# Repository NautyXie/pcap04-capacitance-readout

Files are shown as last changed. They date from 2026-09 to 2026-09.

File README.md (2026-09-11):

# PCAP04 3-Channel Capacitance Readout Board

Open-hardware capacitance-to-digital acquisition board built around the
[ScioSense PCAP04](https://www.sciosense.com/pcap04-capacitance-to-digital-converter/)
CDC and an STM32G0B1. Three floating channel pairs or six grounded electrodes,
brought out on SMA edge connectors, with a single USB-C cable for power,
console and firmware update.

Everything here has been built and measured on real hardware — the numbers in
this README are measurements from an assembled v1.5 board, not datasheet
copy.

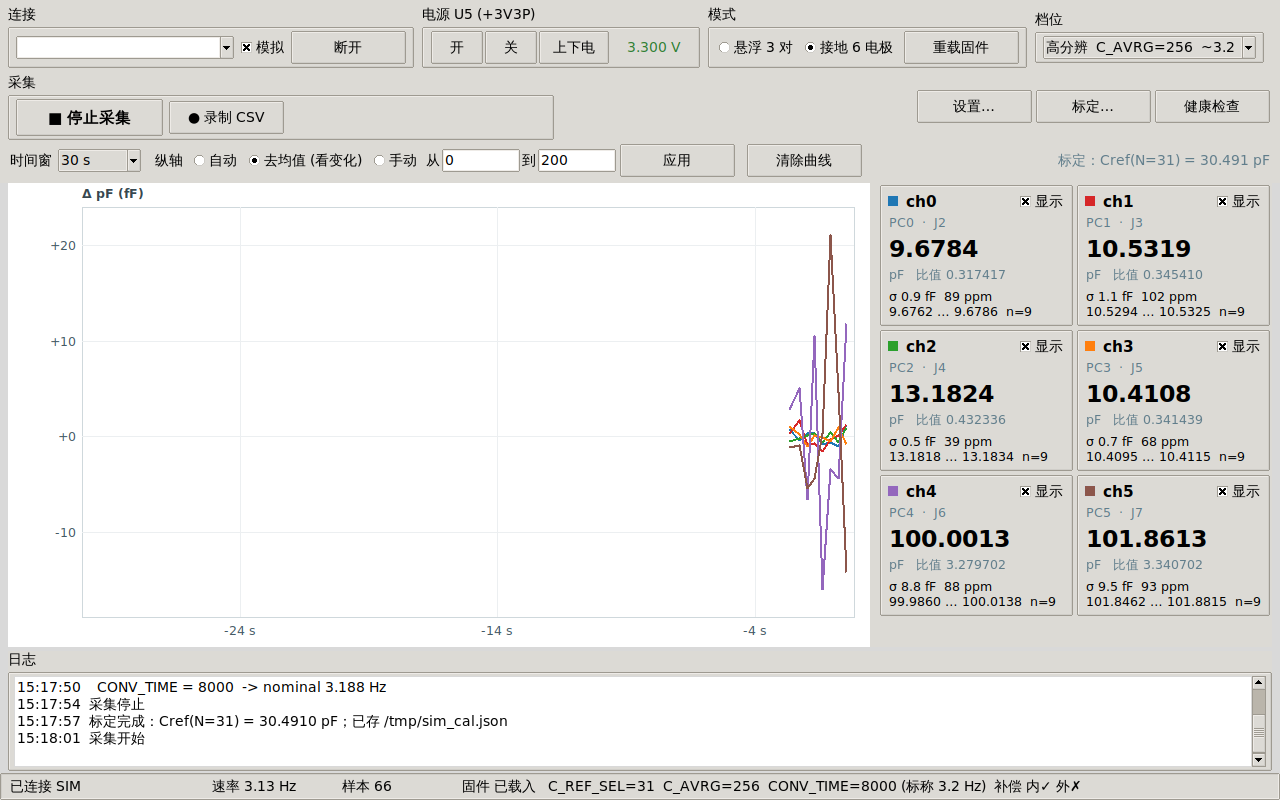
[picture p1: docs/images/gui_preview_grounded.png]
GUI, grounded mode


---

## What it does

| | |
|---|---|
| Channels | 3 floating pairs (PC0/PC1, PC2/PC3, PC4/PC5) **or** 6 grounded electrodes |
| Range | ~385 pF to **1285 pF** full scale, depending on the on-chip reference setting |
| Resolution | sub-aF LSB; **noise floor 4–13 fF** rms depending on averaging and rate |
| Sample rate | 12.8 Hz default, up to **116 Hz** measured |
| Interface | USB-C CDC console (also UART on a header, in parallel) |
| Firmware update | USB DFU — no debug probe needed |
| Board | 100 × 100 mm, 4-layer, SMA edge connectors (C496550) |

Mode switching between floating and grounded takes ~30 ms at runtime; it does
not require re-uploading anything.

## Repository layout

```
hardware/       KiCad 7 project, custom symbols/footprints, 3D models
  manufacturing/  gerbers, drill, IPC netlist
    assembly/       BOM and placement positions
    jlcpcb_pcba/    ready-to-upload JLCPCB assembly packages (BOM + CPL)
firmware/       bare-metal STM32G0B1 firmware (no vendor HAL)
  prebuilt/       pcap04_diag.bin, ready to flash
host/           Python library, CLI and GUI
  characterisation/  the sweeps that produced the numbers in docs/measurements.md
docs/           schematic PDF, design verification report, usage guide,
                measured results
```

## Quick start

### 1. Get a board

`hardware/manufacturing/` contains gerbers, drill files and assembly data ready
to upload. The board is 100 × 100 mm 4-layer; the design rules file is
`hardware/*.kicad_dru`.

For a bare board, upload `PCAP04_v1.5_100mm_C496550_JLCPCB_BARE_BOARD_UPLOAD.zip`.
For an assembled one, use a package under `manufacturing/jlcpcb_pcba/` — but
note that **the PCAP04 itself (LCSC C2829318) is not usually in JLC's assembly
stock and has to be pre-ordered**, and the SMA connectors are hand-soldered.
See [hardware/README.md](hardware/README.md).

### 2. Flash the firmware

No debug probe required — the STM32's ROM bootloader speaks USB DFU, and the
flasher here is pure Python (pyusb, no `dfu-util`):

```bash
cd host
pip3 install -r requirements.txt
python3 pcapdfu.py write ../firmware/prebuilt/pcap04_diag.bin
python3 pcapdfu.py run
```

> A **factory-blank** STM32G0 enters DFU on its own. After the first flash it
> needs one physical unplug/replug of USB-C before it will run your firmware:
> `FLASH_ACR.EMPTY` is only re-evaluated at a power-on reset (RM0444 §2.5.4).
> After that, `python3 pcap.py console dfu` puts it back into DFU on demand.

To build from source you need `arm-none-eabi-gcc`:

```bash
cd firmware && make
```

### 3. Take a measurement

```bash
cd host
python3 pcap.py power on          # U5 load switch -> +3V3P
python3 pcap.py -m f read         # floating, 3 pairs
python3 pcap.py -m g read         # grounded, 6 electrodes
python3 pcap.py stream            # continuous, at the chip's own rate
python3 pcap.py log run.csv -t 60 # 60 s to CSV with running statistics
python3 pcap_gui.py               # graphical strip chart
```

`pcap_gui.py --sim` runs the whole GUI against a built-in simulator, so you can
try the interface before you have a board.

### 4. Calibrate

The chip reports a **ratio** `C / Cref`, so absolute picofarads need one known
capacitor:

```bash
python3 pcap.py calib 100 -c 2    # 100 pF fitted on channel 2
```

Result is stored and loaded automatically from then on.

---

## Things worth knowing before you build one

These cost real debugging time. All measured on the v1.5 board.

**Do not compute Cref from the datasheet formula.** The datasheet gives
`Cref ≈ 0.959·N + 3.23 pF`. This part measures `≈ 0.975·N + 9.91 pF` — the slope
is right to 1.7 % but there is ~7 pF of extra fixed parasitic, and the step
width varies 0.6–1.2 pF between codes (±4 % residual against an affine model).
Calibrate at the code you actually use.

**`DISCHARGE_TIME = 0` breaks real sensors.** The ScioSense reference config
ships with zero discharge time. That is fine for a C0G part on a short trace,
but any sensor with series resistance or a lossy dielectric cannot discharge in
zero time: the port reports `C_PortError` and the reading pins at full scale,
which looks exactly like a dead channel. This firmware defaults to 8. See
[docs/measurements.md](docs/measurements.md).

**`C_AVRG` must stay ≤ 256.** At 512 and above the reading goes ~19.5 % low
(2.4911 → 2.0042 on a 100 pF part). 256 and 257 are both clean, so it is not a
low-byte-zero effect — most likely accumulator saturation with large
capacitances. Firmware and host both clamp.

**A sensor referenced to ground is not a floating sensor.** A level probe
measuring against a tank wall is single-ended. In floating mode the chip
measures the *differential* capacitance between the two ports, and external
compensation deliberately removes each node's capacitance to ground — which is
exactly the signal. The same probe read 0.13 pF floating and 364 pF grounded,
with 36 ppm noise instead of 3800 ppm.

**Config writes need INIT + CDC_START.** Writing a config register alone leaves
the running conversion on the old setting. The first conversion after a restart
is usually garbage (often `0xFFFFFFFF`). The host library handles both.

**The PCAP04's firmware lives in volatile SRAM.** Its NVRAM ships blank, so the
548-byte DSP firmware is uploaded at every power-up. Any reset — a rail cycle or
its own watchdog — zeroes the config registers but **leaves the result
registers holding the previous conversion**, so a dead chip can hand back
plausible-looking stale data. The firmware verifies `RUNBIT` rather than
trusting a cached flag, and the host raises rather than returning stale values.

**Not populated on v1.5:** `PCAUX` (the guard driver output) and the
`PT0REF`/`PT1`/`PTOUT` resistance pins are unrouted, so the integrated guard
driver and external Pt temperature measurement cannot be used on this revision.
`RES6`/`RES7` still return numbers but are only useful as drift indicators.
Route these out if you respin.

---

## Documentation

- [docs/schematic.pdf](docs/schematic.pdf) — rendered schematic, no KiCad needed
- [docs/measurements.md](docs/measurements.md) — every measured figure, and how it was obtained
- [docs/usage.zh.md](docs/usage.zh.md) — full usage guide (Chinese)
- [docs/design-verification-report.pdf](docs/design-verification-report.pdf) — schematic and layout review against the datasheets

## Datasheets

Not redistributed here — they are the vendors' copyrighted documents. Download
from the source:

- PCAP04 — ScioSense
- STM32G0B1 datasheet and RM0444 reference manual — STMicroelectronics
- AN2606 (ROM bootloader) — STMicroelectronics
- TPS22918 load switch, TPS7A20 / TLV755P LDOs, SN74LV125A buffer — Texas Instruments
- USBLC6-2 ESD protection — STMicroelectronics

## Licensing

| Part | Licence |
|---|---|
| `hardware/` | [CERN-OHL-P-2.0](LICENSES/CERN-OHL-P-2.0.txt) |
| `firmware/`, `host/` | [MIT](LICENSES/MIT.txt) |
| `docs/` | [CC-BY-4.0](LICENSES/CC-BY-4.0.txt) |

### Third-party code

`firmware/pcap04_stdfw.h` contains the PCAP04 standard DSP firmware (548 bytes)
and its default configuration (52 bytes), extracted from the
[ScioSense PCAP04 sample code](https://github.com/sciosense/pcap04-sample-code),
which is MIT licensed, **Copyright © 2023 ScioSense**. That copyright notice is
reproduced in the header file. Everything else in `firmware/` is original.

## Contributing

Issues and pull requests welcome. If you build one, a note about what you
measured would be genuinely useful — especially Cref calibration on a different
chip, since the ~7 pF intercept offset documented above is a single-part result
and may or may not be typical.

## Disclaimer

This is a research instrument, published as-is with no warranty. It has been
verified on one assembled board by one person. Check it against your own
requirements before relying on it for anything that matters.

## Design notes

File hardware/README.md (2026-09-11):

# Hardware

KiCad 7 project for the PCAP04 3-channel capacitance readout board.
100 × 100 mm, 4 layers, SMA edge connectors.

Licence: **CERN-OHL-P-2.0** (permissive). See `../LICENSES/CERN-OHL-P-2.0.txt`.

## Files

```
PCAP04_Acquisition_3CH_v1.5_100mm_C496550.kicad_pro   project
                                          .kicad_sch   root sheet
                                          .kicad_pcb   layout
                                          .kicad_dru   design rules
MCU_CONTROL.kicad_sch      STM32G0B1, SWD, USB, console header
USB_POWER.kicad_sch        USB-C input, protection, rails, U5 load switch
PCAP04_Acquisition.lib     custom symbols
PCAP04_Custom.pretty/      custom footprints
sym-lib-table              symbol library table
fp-lib-table               footprint library table
3dmodels/                  3D models for the custom parts
manufacturing/
  gerber/  drill/            bare-board fabrication
  *_JLCPCB_BARE_BOARD_UPLOAD.zip   the same, zipped for upload
  *_IPC-D-356.net            netlist for electrical test
  assembly/                  KiCad BOM (all / fitted) and placement positions
  jlcpcb_pcba/               ready-to-upload JLCPCB assembly packages
    smt_only/                  49 SMT placements, no through-hole
    j11_fitted/                the same plus the J11 power-select header
```

A rendered schematic is at `../docs/schematic.pdf`, and board renders are in
`../docs/images/`, so you can read the design without installing KiCad.

## Getting one made

`manufacturing/` is ready to upload as-is. It was produced for and verified at
JLCPCB, but the gerbers are standard.

- 4 layers, 1.6 mm, HASL or ENIG both fine
- the SMA edge connectors are C496550 (LCSC part number)

For **bare boards**, upload `manufacturing/PCAP04_v1.5_100mm_C496550_JLCPCB_BARE_BOARD_UPLOAD.zip`
and nothing else.

For **assembled boards**, pick one of the two packages under
`manufacturing/jlcpcb_pcba/` and follow the README inside it — each lists the
exact BOM and CPL files to upload and what is deliberately left unfitted. Two
things there are worth reading before you pay:

- **U1 (PCAP04-AQFM-24, LCSC C2829318) is not normally in JLC's assembly
  stock.** It has to be pre-ordered into My Parts Lib. No substitution is
  acceptable.
- **The SMA connectors J2–J7 are not assembled.** They are edge-mount parts;
  solder them by hand. Same for the headers, except J11 in the `j11_fitted`
  package.

`assembly/` holds the plain KiCad exports (BOM and placement positions) if you
want to feed a different assembler or hand-build.

## Layer stack and why it matters here

| Layer | Use |
|---|---|
| L1 F.Cu | components, sense lines |
| L2 In1.Cu | ground plane |
| L3 In2.Cu | power and signal |
| L4 B.Cu | chassis pour |

The sense traces to the SMA connectors want a continuous ground plane directly
underneath. Measured trace capacitance follows

```
C = 4.18 pF + 0.158 pF/mm
```

for five of the six electrodes, within ±3 %. **PC4 is 20 % off** because it is
routed on L4 under the chassis pour rather than over the ground plane. That was
flagged in the design review before assembly and then confirmed by measurement
— see `../docs/measurements.md` §3. Fix it if you respin.

## Known limitations of v1.5

**`PCAUX` is not routed.** That pin is the PCAP04's integrated guard driver
output. Without it, guarding (`C_G_EN`) cannot be used, which matters if you
want long cables to remote electrodes.

**`PT0REF` / `PT1` / `PTOUT` are not routed.** The resistance-to-digital
converter therefore has no external reference resistor, so external Pt
temperature measurement is unavailable. `RES6`/`RES7` still return numbers, but
treat them only as drift indicators.

**RPS1 was assembled as 33 kΩ where the BOM says 330 kΩ.** This is an assembly
deviation on the built board, not a design error — it changes the +3V3P sense
divider to 133/100. The firmware compensates (`board.h`, `RAIL_DIV_NUM`), and
the `div` console command overrides it. Check what is actually fitted on yours.

If you respin, routing `PCAUX` and the PT pins out to test points would be the
two highest-value changes.

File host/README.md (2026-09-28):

# Host tools

Python library, command line and GUI. Licence: **MIT**.

```bash
pip3 install -r requirements.txt
```

`pyserial` is the only hard requirement. `pyusb` + `libusb-package` are needed
for DFU flashing; `pyocd` only if you use a CMSIS-DAP probe over SWD.

## Files

| | |
|---|---|
| `pcap04.py` | the library: `PCap04`, `Sample`, `Calibration` |
| `pcap.py` | command line |
| `pcap_gui.py` | tkinter GUI with a strip chart; `--sim` needs no hardware |
| `pcapdfu.py` | USB DFU flasher, pure Python |
| `pcapflash.py` | SWD flasher via pyOCD (optional) |
| `swdlib.py` | shared pyOCD helpers |
| `characterisation/` | the sweeps behind `../docs/measurements.md` |

## Library

```python
from pcap04 import PCap04

with PCap04() as d:
    d.power(True)
    d.load('f')                     # or d.mode('g') to switch at runtime
    d.speed('precise')
    for s in d.stream(100):
        print(s.pf)                 # [ch0, ch1, ch2] in picofarads
        if s.errors:
            print(s.errors)
```

`Sample` exposes `.raw` `.ratios` `.channels` `.pf` `.status` `.errors`
`.por_flags` `.runbit` `.is_open(i)`.

## Three traps this code exists to avoid

**Console framing.** The firmware prints `> ` when ready. Some commands sit in a
500 ms delay mid-output, so waiting for a silent gap returns early and the *next*
command is written while the firmware is not listening — dropped with no error.
Everything here waits for the prompt.

**Duplicate samples.** Polling faster than the conversion rate re-reads the same
registers, and a naive standard deviation then comes out as exactly 0.
`stream()` is gated on INTN in firmware; `read()` de-duplicates on the raw word;
`stats()` raises rather than reporting zero variance.

**Stale data after a reset.** A PCAP04 power-on reset zeroes the config
registers but leaves the *result* registers holding the previous conversion, so
a dead chip hands back plausible numbers. `read()` checks `RUNBIT` and raises;
pass `allow_stale=True` if you want to inspect them anyway.

There is also an advisory lock on the serial port: two processes opening
`/dev/cu.*` on macOS does not error, it just interleaves bytes and looks exactly
like wedged hardware. Linux/macOS retain this `fcntl` file lock. On Windows,
pyserial opens the serial port exclusively, so no `fcntl` module or lock file
is needed; a second open fails with `serial.SerialException`.

## Calibration

The chip reports `C / Cref`. One known capacitor turns that into picofarads:

```bash
python3 pcap.py calib 100 -c 2            # 100 pF on channel 2
python3 pcap.py calib 100 -c 2 --sweep    # characterise all 31 reference codes
```

Stored in `pcap04_calibration.json` (gitignored — it is specific to your board)
and loaded automatically afterwards.

## Full configuration editor

The GUI **前端参数** button exposes 90 named user fields, including the
10/180 kΩ charging resistor and precharge/full-charge timing. It reads the
actual configuration, pauses acquisition, applies only edits with RUNBIT held
low, verifies readback, and supports JSON snapshots. No firmware reflash is
required. See [configuration controls](../docs/register-controls.md) for timing,
protected fields, CLI/API examples and the hardware-validation boundary.

```sh
python3 pcap.py registers --list
python3 pcap.py registers
```

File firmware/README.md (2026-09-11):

# Firmware

Bare-metal STM32G0B1CBT6 firmware. No vendor HAL, no CubeMX — every register
definition in `stm32g0b1.h` was written by hand against RM0444 Rev 6 and
DS13560 Rev 6.

Licence: **MIT**. `pcap04_stdfw.h` additionally carries ScioSense's MIT notice;
see the top of that file and `../LICENSE`.

## Build

```bash
make                # needs arm-none-eabi-gcc
```

~22 KB of the 128 KB flash. A prebuilt binary is in `prebuilt/`.

## Flash

```bash
cd ../host
python3 pcapdfu.py write ../firmware/prebuilt/pcap04_diag.bin
python3 pcapdfu.py run
```

See the top-level README for the one-time power-cycle caveat on a blank chip.

## Source map

| File | |
|---|---|
| `main.c` | clocks, GPIO, ADC, SPI, PCAP04 driver, console, commands |
| `usb_cdc.c/.h` | USB CDC-ACM device, polled, ~600 lines |
| `stm32g0b1.h` | register definitions, hand-verified against RM0444 |
| `board.h` | pin map, PCAP04 opcodes, board constants |
| `startup.c` | vector table and reset handler |
| `stm32g0b1cb.ld` | linker script; `.noinit` holds the double-tap magic word |
| `pcap04_stdfw.h` | ScioSense DSP firmware + default config (third-party, MIT) |

## Design notes

**Three console transports in parallel** — USB CDC, UART on J10, and an SWD
mailbox — and the main loop reads whichever speaks first. Keeping the UART alive
means a USB regression can never lock you out of the board.

**No interrupts except SysTick.** USB is polled from the main loop, so it cannot
perturb the SPI timing of a conversion in progress. Every hardware wait is
bounded with a per-peripheral timeout rather than a bare `while (!(REG & FLAG))`,
and `info` reports which ones ever fired.

**Escape hatch.** Double-tap RESET within 400 ms and the board enters the ROM
bootloader regardless of what the application firmware is doing. The magic word
lives in `.noinit`. `usb_cdc_detach()` runs first so the ROM's USB comes up on a
clean bus.

**Clocks.** HSI16 → PLL(M=1, N=8, R=÷2) → 64 MHz core, 2 flash wait states.
USB runs from HSI48 trimmed by the CRS against USB SOF packets — there is no
crystal on this board. Note `PLLR` encoding: `001` is ÷2, `000` is Reserved.

## Console commands

`help` lists them all. The ones you will actually use:

```
rail on|off          U5 load switch for the PCAP04 supply
load | loadf         upload the DSP firmware, grounded / floating
mode g|f             switch mode at runtime (~30 ms)
stream [n]           one line per conversion, gated on INTN
resd                 RES0..RES7 as Q5.27 ratios
avrg / conv / refsel / disch / comp / ports    front-end parameters
params               decode the current configuration
health               decode STATUS_0/1/2, INTN, rail voltage
usb                  CDC link state, bus resets, dropped bytes
dfu                  enter the ROM bootloader for reflashing
```

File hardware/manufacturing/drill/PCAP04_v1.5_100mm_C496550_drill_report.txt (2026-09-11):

Drill report for PCAP04_Acquisition_3CH_v1.5_100mm_C496550.kicad_pcb
Created on 2026-08-25T17:33:02

Copper Layer Stackup:
    =============================================================
    L1 :  F.Cu                      front
    L2 :  GND_PLANE                 in1
    L3 :  POWER_SIGNAL              in2
    L4 :  B.Cu                      back

Drill file 'PCAP04_Acquisition_3CH_v1.5_100mm_C496550-PTH.drl' contains
    plated through holes:
    =============================================================
    T1  0.300mm  0.0118"  (5 holes))
    T2  0.400mm  0.0157"  (90 holes))
    T3  0.600mm  0.0236"  (4 holes)  (with 4 slots)
    T4  1.000mm  0.0394"  (16 holes))

    Total plated holes count 115

Drill file 'PCAP04_Acquisition_3CH_v1.5_100mm_C496550-NPTH.drl' contains
    unplated through holes:
    =============================================================
    T1  0.650mm  0.0256"  (2 holes))

    Total unplated holes count 2

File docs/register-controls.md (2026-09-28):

# PCAP04 configuration editor / 全参数控制

The **前端参数** button now opens a grouped, scrollable editor for **90 user
configuration fields** from the ScioSense PCAP04 Rev.6 datasheet, §6.3.
The GUI, Python API, CLI and simulator share `host/pcap_registers.py`.

## Starting it / 启动

```sh
cd host
python3 pcap_gui.py --sim      # GUI demonstration, no serial hardware
python3 pcap_gui.py           # actual board, local serial port
python3 pcap_gui.py --port /dev/ttyACM0
```

A board attached to a Raspberry Pi needs a host able to access its serial port.
This change does not add an SSH serial transport. The GUI needs a graphical Tk
session; use the CLI over SSH for a headless Pi.

## Slower charging / 减慢充电

`RCHG_SEL=0` selects **10 kΩ**; `RCHG_SEL=1` selects **180 kΩ**.
`PRECHARGE_TIME` allocates time through that resistor; **1023 disables**
precharge. `FULLCHARGE_TIME` allocates the final direct charge; 1023 disables
that phase. Increasing a duration alone does not change the RC time constant.
The full-charge phase still has an unresisted edge. Allow sufficient settling
and verify the waveform/readout for the actual capacitance and cable.

No fixed timing value is recommended without checking the configured clock.
For cycle period `t_cycle` (datasheet §7.2.3.1–2):

| Phase | OLF | OHF |
| --- | --- | --- |
| Precharge, enabled | `(n+1)*t_cycle` | `(n+1)*t_cycle`, or `(n+2)*t_cycle` if full-charge disabled |
| Full charge, enabled | `(n+1)*t_cycle` | `(n+2)*t_cycle` |
| Discharge | `(n+1)*t_cycle` | `n*t_cycle` |

The datasheet is inconsistent about discharge code 1023 (Table 22 says off;
Table 67 gives a duration). It remains representable and is labelled with that
ambiguity; it is not a suggested operating value. The detailed CFG17 table is
used for FULLCHARGE_TIME high bits, despite the overview's DISCHARGE_TIME typo.
Guard attenuation has inconsistent units in Tables 29/70; the editor exposes
the code without inventing a physical unit.

## Workflow / 使用流程

1. Connect, power/load explicitly if needed, then open **前端参数**. Opening the
   editor pauses streaming and closes any current CSV recording.
2. Read values from hardware. No guessed defaults and no implicit firmware load.
3. Edit decimal or `0x` hexadecimal values. Apply writes **only changed fields**.
   A final configuration is validated before the first write. A field changed
   externally since the snapshot is rejected and must be refreshed.
4. RUNBIT is cleared, shared register bits are preserved, and every byte is
   read back. The complete configuration is verified before and after INIT/
   CDC_START. RUNBIT stays off if requested. On failure, the host attempts to
   clear RUNBIT and reports partial changes; it does not silently roll back or
   resume acquisition.
5. Start a new acquisition manually. The first two streamed samples after an
   editor write are discarded. Changing gain/reference topology/compensation
   clears the session's pF calibration; the saved calibration file is retained.
6. **导出JSON** saves the last readback snapshot, not unapplied edits.
   **导入JSON** fills fields only; it does not write until Apply is clicked.

The ordinary channel plot does not decode differential mode and does not
support every trigger configuration. The GUI prevents starting that plot with
RUNBIT off, PG5 INTN disabled, differential mode, or a noncontinuous trigger.
The controls remain available for these modes; use the raw console/results for
specialized acquisition. Changes to the OLF invalidate the old nominal 51 kHz
rate estimate. Measured rate remains the meaningful observation.

## CLI and Python / 命令行与接口

```sh
python3 pcap.py registers --list                # offline field catalog
python3 pcap.py -p /dev/ttyACM0 registers        # current decoded fields
# Example only: choose timings for the actual clock and sensor first.
python3 pcap.py -p /dev/ttyACM0 registers \
  --set RCHG_SEL=1 --set PRECHARGE_TIME=50
```

```python
from pcap04 import PCap04
with PCap04(port='/dev/ttyACM0') as dev:
    fields = dev.read_fields()
    # Assumes the user has explicitly powered and loaded the board.
    result = dev.write_fields({'RCHG_SEL': 1, 'PRECHARGE_TIME': 50},
                              expected={'RCHG_SEL': fields['RCHG_SEL'],
                                        'PRECHARGE_TIME': fields['PRECHARGE_TIME']})
    print(result['registers'])
```

`set_precharge(n)`, `set_fullcharge(n)` and `set_charge_resistor(code)` are
convenience wrappers. Callers must close an active stream before register I/O;
the GUI does that through its single serial worker. API callers should discard
initial conversions after a restart. A deliberately stopped/failed edit will
not be implicitly overwritten by `read()` or `stream()` in that connection;
explicit `load()` or a successful RUNBIT=1 edit is needed.

## Scope / 覆盖边界

Tabs cover charge/discharge, CDC, clocks/runtime, guard, RDC temperature,
DSP/GPIO, PWM/PDM, and firmware-defined algorithm fields. The full hardware
C_AVRG range 0..8191 is available, with the existing board-specific warning:
values above 256 are unvalidated and ≥512 previously read low. Legacy
`config --avrg` and speed presets retain their existing clamp.

Reserved, mandatory internal/TDC and factory CHARGE_PUMP bits are shown in the
raw snapshot but never edited. OX_AUTOSTOP_DIS, OX_STOP, RDCHG_OPEN and
HS_MODE_SEL are manufacturer internal controls, not user parameters.
MEM_LOCK, SERIAL_NUMBER and MEM_CTRL are special protection/nonvolatile
operations, excluded from this runtime editor. **No NVRAM store/erase is sent.**
RAM configuration disappears on power cycle or explicit load. Algorithm fields
marked linearize-only do not acquire that behavior with the bundled standard
DSP firmware. Guard requires correctly wired hardware; it is distinct from the
passive outer shield connected to PCB GND.

## Compatibility and verification

Uses existing MCU commands `cfg`, `wr`, `init`, `start`; no firmware binary
change or board flashing is needed. Verified with protocol fault-injection
unit tests and the native Tk simulator smoke test. This is **not hardware timing,
noise, or calibration validation**; no physical board was changed by development.
The simulator exercises configuration/readback, not the analog effects of each
advanced setting.

```sh
python3 -m unittest discover -s tests -v
python3 tests/gui_smoke.py   # needs working Tk/display, simulator only
```

Source: [ScioSense PCAP04 datasheet Rev.6, 2023-09-25](https://www.sciosense.com/wp-content/uploads/2023/12/PCAP04-Datasheet.pdf).

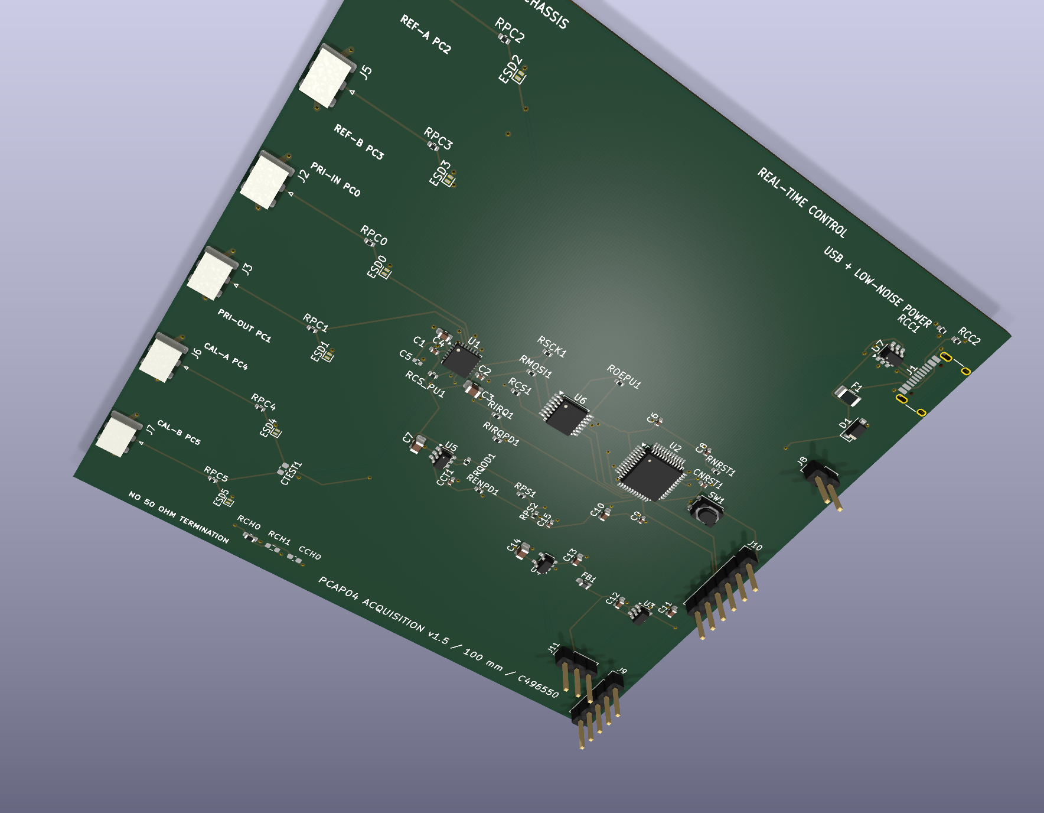
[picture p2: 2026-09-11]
docs/images/board_3d.png

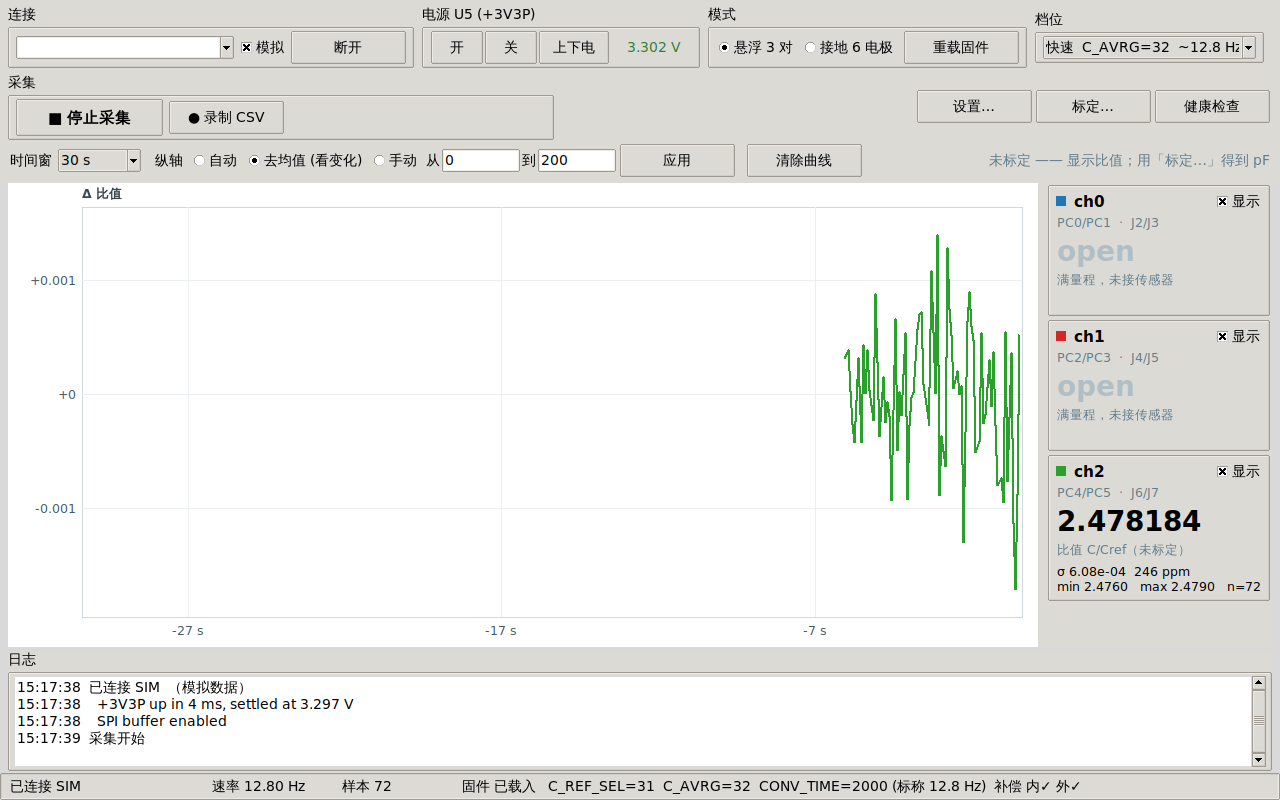
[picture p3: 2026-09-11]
docs/images/gui_preview_floating.png

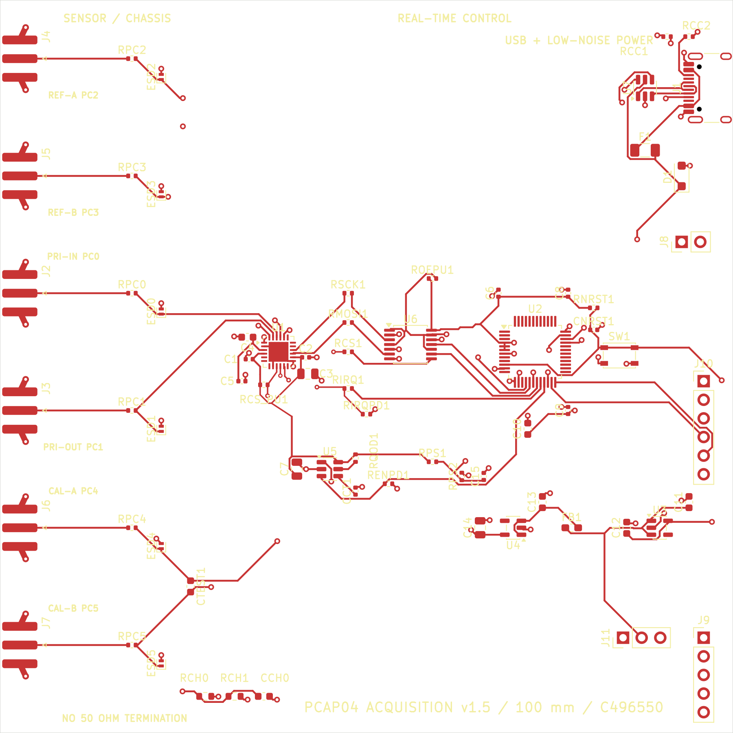
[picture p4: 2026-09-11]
docs/images/pcb_top.png

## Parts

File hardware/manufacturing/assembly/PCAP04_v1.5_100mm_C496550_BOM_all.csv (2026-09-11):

Refs | Value | Footprint | Datasheet | Qty | DNP
C1,C2,C6,C8,C9,CNRST1 | 100n | Capacitor_SMD:C_0402_1005Metric |  | 6
C3,C7,C14 | 10u | Capacitor_SMD:C_0805_2012Metric |  | 3
C4,C10,C12 | 4.7u | Capacitor_SMD:C_0603_1608Metric |  | 3
C5 | 100n_DNP | Capacitor_SMD:C_0402_1005Metric |  | 1 | DNP
C11,C13 | 1u | Capacitor_SMD:C_0603_1608Metric |  | 2
C15 | 10n_C0G | Capacitor_SMD:C_0402_1005Metric |  | 1
CCH0 | 1n_DNP | Capacitor_SMD:C_0603_1608Metric |  | 1 | DNP
CCT1 | 1n | Capacitor_SMD:C_0402_1005Metric |  | 1
CTEST1 | 100pF_C0G_0.1%_DNP | Capacitor_SMD:C_0603_1608Metric |  | 1 | DNP
D1 | SMF5.0A | Diode_SMD:D_SOD-123F |  | 1
ESD0-ESD5 | DNP | Diode_SMD:D_SOD-882 |  | 6 | DNP
F1 | 500mA_PTC | Fuse:Fuse_1206_3216Metric |  | 1
FB1 | 600R@100MHz | Inductor_SMD:L_0603_1608Metric_Pad1.05x0.95mm_HandSolder |  | 1
J1 | USB-C_USB2_DEVICE | Connector_USB:USB_C_Receptacle_HRO_TYPE-C-31-M-12 |  | 1
J2-J7 | BWSMA-KE-P001 / C496550 | PCAP04_Custom:SMA_Bat_Wireless_BWSMA-KE-P001_EdgeMount_1.6mm-PCB |  | 6
J8 | EXT_5V_LOW_NOISE | Connector_PinHeader_2.54mm:PinHeader_1x02_P2.54mm_Vertical |  | 1
J9 | SWD | Connector_PinHeader_2.54mm:PinHeader_1x05_P2.54mm_Vertical |  | 1
J10 | UART_HOST | Connector_PinHeader_2.54mm:PinHeader_1x06_P2.54mm_Vertical |  | 1
J11 | 5V_SOURCE_SELECT | Connector_PinHeader_2.54mm:PinHeader_1x03_P2.54mm_Vertical |  | 1
RCC1,RCC2 | 5.1k_1% | Resistor_SMD:R_0402_1005Metric |  | 2
RCH0 | 0R_FITTED | Resistor_SMD:R_0603_1608Metric |  | 1
RCH1 | 1M_DNP | Resistor_SMD:R_0603_1608Metric |  | 1 | DNP
RCS1,RMOSI1,RSCK1 | 33R | Resistor_SMD:R_0402_1005Metric |  | 3
RCS_PU1,RENPD1,ROEPU1,RPS2 | 100k | Resistor_SMD:R_0402_1005Metric |  | 4
RIRQ1 | 1k | Resistor_SMD:R_0402_1005Metric |  | 1
RIRQPD1,RNRST1 | 10k | Resistor_SMD:R_0402_1005Metric |  | 2
RPC0-RPC5 | 0R | Resistor_SMD:R_0402_1005Metric |  | 6
RPS1 | 330k | Resistor_SMD:R_0402_1005Metric |  | 1
RQOD1 | 470R | Resistor_SMD:R_0402_1005Metric |  | 1
SW1 | RESET | Button_Switch_SMD:SW_SPST_PTS810 |  | 1
U1 | PCAP04-AQFM-24_V2 | Package_DFN_QFN:QFN-24-1EP_4x4mm_P0.5mm_EP2.7x2.7mm |  | 1
U2 | STM32G0B1CBT6 | Package_QFP:LQFP-48_7x7mm_P0.5mm |  | 1
U3 | TLV75533PDBVR | Package_TO_SOT_SMD:SOT-23-5 |  | 1
U4 | TPS7A2033PDBVR | Package_TO_SOT_SMD:SOT-23-5 |  | 1
U5 | TPS22918DBVR | Package_TO_SOT_SMD:SOT-23-6 | https://www.ti.com/lit/ds/symlink/tps22918.pdf | 1
U6 | SN74LV125APWR | Package_SO:TSSOP-14_4.4x5mm_P0.65mm |  | 1
U7 | USBLC6-2SC6 | Package_TO_SOT_SMD:SOT-23-6 |  | 1

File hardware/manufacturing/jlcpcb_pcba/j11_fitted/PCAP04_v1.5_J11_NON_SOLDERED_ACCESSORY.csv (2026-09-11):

Item | Qty per board | LCSC Part # | Installation | Source
2.54mm removable jumper cap | 1 | C5305 | Install on J11 pins 1-2 after wave soldering; this part is not soldered. | https://jlcpcb.com/partdetail/BOOMELE_Boom_Precision_Elec-C5305/C5305

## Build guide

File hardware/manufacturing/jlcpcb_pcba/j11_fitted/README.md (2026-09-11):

# PCAP04 v1.5 - JLCPCB PCBA handoff (J11 fitted)

Files to upload separately:

1. Bare-board Gerber ZIP: ../../PCAP04_v1.5_100mm_C496550_JLCPCB_BARE_BOARD_UPLOAD.zip
2. BOM: PCAP04_v1.5_100mm_JLCPCB_PCBA_J11_BOM.csv
3. CPL: PCAP04_v1.5_100mm_JLCPCB_PCBA_J11_CPL.csv
4. Non-soldered accessory list: PCAP04_v1.5_J11_NON_SOLDERED_ACCESSORY.csv

Frozen scope:

- Fit 49 top-side SMT placements plus J11 through-hole header C49257.
- Do not fit J2-J7 SMA or J8-J10 headers.
- J11 is a wave-soldering part and may add a through-hole assembly fee.
- The C5305 jumper cap is a removable accessory; it is not soldered. Install it on J11 pins 1-2 for default USB 5 V. Ask JLC to install it as a manual operation, or fit it after delivery.
- U1 must be PCAP04-AQFM-24 / C2829318 with no substitution; add/pre-order it during the order.
- U5 must be TPS22918DBVR / C131941. Verified mapping: 1 VIN, 2 GND, 3 ON, 4 CT, 5 QOD, 6 VOUT.

Before payment:

- Confirm all 28 BOM rows match the exact LCSC numbers.
- Confirm J11 is matched to C49257 and listed for wave soldering.
- Add assembly note: install C5305 jumper cap on J11 pins 1-2; otherwise install it by hand after delivery.
- Confirm the JLC placement preview for U1-U7 pin-1, D1 cathode, and J1 orientation.
- Confirm C2829318 has been allocated to this order in My Parts Lib.
- Do not accept automatic substitutions.

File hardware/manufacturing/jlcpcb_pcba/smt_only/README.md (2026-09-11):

# PCAP04 v1.5 - JLCPCB SMT-only handoff

Files to upload separately:

1. Bare-board Gerber ZIP: ../../PCAP04_v1.5_100mm_C496550_JLCPCB_BARE_BOARD_UPLOAD.zip
2. BOM: PCAP04_v1.5_100mm_JLCPCB_SMT_ONLY_BOM.csv
3. CPL: PCAP04_v1.5_100mm_JLCPCB_SMT_ONLY_CPL.csv

Frozen scope:

- Fit 49 top-side SMT placements.
- Do not fit J2-J7 SMA or J8-J11 headers.
- The J11 jumper cap is a removable accessory; it is not soldered and is not in the BOM.
- U1 must be PCAP04-AQFM-24 / C2829318 with no substitution. Public JLC assembly stock was 0 when checked; pre-order/global-source it into My Parts Lib first.
- U5 must be TPS22918DBVR / C131941. Verified mapping: 1 VIN, 2 GND, 3 ON, 4 CT, 5 QOD, 6 VOUT.

Before payment:

- Confirm all 27 BOM rows match the exact LCSC numbers.
- Confirm the JLC placement preview for U1-U7 pin-1, D1 cathode, and J1 orientation.
- Confirm C2829318 has been allocated to this order in My Parts Lib.
- Do not accept automatic substitutions.

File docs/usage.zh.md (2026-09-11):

# PCAP04 前端使用说明

固件 **v3.1.0** + 主机端 `pcap04.py`（库）/ `pcap.py`（命令行）/ `pcap_gui.py`（图形界面）。

装依赖：`pip3 install pyserial`。

**接线：一根 USB-C 线就够了。** 从 v3.1.0 起固件自带 USB CDC 控制台，
供电、控制台、烧录全走板子自己的 USB-C（J11 跳帽必须在）。
Debug Probe 不再需要 —— 但 J10 上的 UART 控制台仍然并行工作，作为后备。

主机端按 VID/PID (`1209:0001`) 认板子自己的口，不会误抓 Debug Probe 的口。

---

## 1. 三通道悬浮 / 接地

```bash
./pcap.py -m f read          # 悬浮：3 对电极
./pcap.py -m g read          # 接地：6 个单端电极
```

```
ch0 PC0/PC1 J2/J3  --- open ---
ch1 PC2/PC3 J4/J5  --- open ---
ch2 PC4/PC5 J6/J7     99.9706 pF   (ratio 2.490443)
```

通道编号：

| 模式 | 通道 | PCAP04 端口 | 板上连接器 |
|---|---|---|---|
| 悬浮 | ch0 / ch1 / ch2 | PC0+PC1 / PC2+PC3 / PC4+PC5 | J2+J3 / J4+J5 / J6+J7 |
| 接地 | ch0…ch5 | PC0…PC5 | J2…J7 |

**运行时切换约 30 ms**（只改 3 个配置寄存器 + INIT + CDC_START），不用重新上传 548 字节固件。
只有掉电或芯片复位之后才需要完整重载，加 `--reload`。

实测（CTEST1 的 100 pF 跨在 PC4/PC5）：

```
悬浮  ch2 = 99.87 / 99.96 / 99.97 pF          对着 100 pF 标准
接地  12.81 / 13.94 / 17.45 / 13.78 / 132.36 / 134.82 pF
      前四个是裸电极走线电容，PC4/PC5 偏高是对的 —— CTEST1 正好跨在它俩之间
```

> **没接传感器的通道读数没有意义。** 默认配置下空悬通道会顶到满量程（显示 `--- open ---`），
> 但把 C_AVRG 提高之后它们会停在某个不满量程的值（见过 13.8，折算 554 pF）。
> 那不是电容，只是补偿算法在没有被测件时的输出。工具没法可靠区分，**以你实际焊了什么为准**。

---

## 2. U5 电源开关

U5 是 TPS22918 负载开关，控制 PCAP04 的 +3V3P。

```bash
./pcap.py power on           # 开（同时使能 U6 SPI 缓冲器）
./pcap.py power off          # 先把 SPI 缓冲器置高阻，再断电
./pcap.py power cycle        # 完整上下电
```

```
  +3V3P up in 4 ms, settled at 3.297 V
```

`power off` 会先 `bus off` 再断电，避免 SPI 缓冲器往一颗没供电的芯片上灌电流。
放电时间实测约 43 ms（RQOD1 470 Ω + 开关内部 25 Ω 对 20 µF），所以 `power_cycle()`
默认断电 200 ms 是充裕的。

**掉电之后 PCAP04 的 SRAM 固件就没了**，配置寄存器全变 0。`health` 会看到
`RUNBIT CLEAR - chip is idle`。下一条命令加 `--reload` 恢复：

```bash
./pcap.py power cycle
./pcap.py -m f --reload read
```

---

## 3. 连续采集与记录

```bash
./pcap.py stream             # 实时打印，Ctrl-C 停
./pcap.py stream -n 200
./pcap.py log run.csv -t 60  # 60 秒到 CSV，同时滚动显示均值/标准差
```

**采样由固件里的 INTN 引脚下降沿触发**，每一帧都是一次真正的新转换，跑在芯片自己的
转换速率上（默认 12.8 Hz），不再受控制台一问一答限制（原来约 3 Hz）。
这也从根上堵死了"轮询快于转换速率导致重复采样、标准差算出来是 0"的坑。

CSV 每行包含：主机时间、板上毫秒时标、各通道原始 32 位值 / 比值 / pF、三个状态寄存器、错误标志。

实测 40 个样本：

```
  ch2 PC4/PC5 J6/J7  mean 100.001896 pF  sd 0.0051 (51.0 ppm)  drift +0.00493  n=40
```

---

## 4. 标定（拿到真正的 pF）

```bash
./pcap.py calib 100 -c 2              # 用 ch2 上已知的 100 pF 标定
./pcap.py calib 100 -c 2 --sweep      # 顺便把整个参考电容阵列扫一遍（约 2 分钟）
```

结果存 `pcap04_calibration.json`，之后所有命令自动加载并直接显示 pF。

```
  Cref(N=31) = 40.1417 pF
  ch2 trace-to-ground parasitic (removed by C_COMP_EXT) = 22.138 pF
```

**不要用数据手册公式算 Cref。** 手册给 `0.959·N + 3.23 pF`，这颗实测是
`≈0.975·N + 9.91 pF` —— 斜率对得上（差 1.7 %），但多了约 +7 pF 的固定寄生，
而且步长在 0.6…1.2 pF 之间起伏，对仿射模型残差 ±4 %。所以标定值是**按 C_REF_SEL 码逐档存的**，
不是算出来的。做绝对测量时要在你实际使用的那一档上标定。

---

## 5. 速度 / 分辨率档位

```bash
./pcap.py speed fast         # C_AVRG=32,  CONV_TIME=2000
./pcap.py speed balanced     # C_AVRG=128, CONV_TIME=2000
./pcap.py speed precise      # C_AVRG=256, CONV_TIME=8000
```

设完之后会实测速率和噪声：

```
fast       rate 12.77 Hz   sd 242 ppm   noise 24.2 fF
balanced   rate 12.86 Hz   sd  85 ppm   noise  8.5 fF
precise    rate  3.23 Hz   sd  60 ppm   noise  6.0 fF
```

（折算到 100 pF 传感器。手册标称浮空全补偿 19 aF @ 10 Hz，那是 10 pF 基准、
最大平均深度、评估板 + C0G 电容、且转换期间不跑 SPI 的条件。本板高约 250 倍，
差异来源见 README 的噪声一节。）

**C_AVRG 不能超过 256。** 实测 ≥512 时读数系统性偏低 19.5 %（2.4911 → 2.0042），
256 和 257 都正常，所以不是"低字节为 0"的问题，更像大电容下累加器饱和。
固件和主机端都会拦下来。

---

## 6. 其他

```bash
./pcap.py health             # 解码 STATUS_0/1/2、INTN、电源轨
./pcap.py config             # 当前前端参数
./pcap.py config --refsel 24 --avrg 128 --comp ie --ports 0x3F
./pcap.py console "wr 04 B1" # 原始固件命令
```

`--comp` 取 `i`（片内）、`e`（片外）、`ie`、或空。片外补偿只在悬浮模式合法
（手册：`C_COMP_EXT` must be avoided when `C_FLOATING == 0`），接地模式下会被拒绝。

**关于"温度测量"**：这块板子上 PCAUX、PT0REF、PT1、PTOUT 全都没有走线，
所以**外部 Pt 电阻温度测量和屏蔽驱动（guard）在硬件上就用不了**。
RES6/RES7 仍会返回数值，但没有外部参考电阻，不能当绝对温度用 —— 最多当漂移指示。
如果后面要用，PCAUX 和 PT 那几个脚需要在下一版板子上引出来。

---

## 7. 库用法

```python
from pcap04 import PCap04

with PCap04() as d:
    d.power(True)
    d.load('f')                     # 或 d.mode('g') 运行时切换
    d.speed('precise')
    for s in d.stream(100):
        print(s.pf)                 # [ch0, ch1, ch2] 单位 pF
        if s.errors:
            print(s.errors)         # RUNBIT_CLEAR / PORT_ERR_PCn / ERR_OVFL ...
```

`Sample` 提供 `.raw` `.ratios` `.channels` `.pf` `.status` `.errors` `.por_flags`
`.runbit` `.is_open(i)`。

`PCap04.stats(samples, channel)` 给均值/标准差/峰峰/ppm/实测速率，
并且在所有样本完全相同时**主动报错**而不是返回标准差 0 —— 那种情况一定是重复采样。

同一个串口同时被两个进程打开时会直接报错（文件锁），不会静默地把数据搅乱。

---

## 8. 图形界面

```bash
python3 pcap_gui.py            # 连板子
python3 pcap_gui.py --sim      # 没有板子：内置模拟器，布局和功能完全一样
```

只依赖 tkinter + pyserial（模拟模式连 pyserial 都不用），不需要 matplotlib。

布局（从上到下）：

- **连接**：串口下拉 / 「模拟」勾选 / 连接-断开
- **电源 U5**：开 / 关 / 上下电，右边实时显示 +3V3P 电压（绿色 = 正常）
- **模式**：悬浮 3 对 ↔ 接地 6 电极，运行时切换；「重载固件」= 完整重传（掉电后用）
- **档位**：快速 / 平衡 / 高分辨（就是 CLI 的 speed 三档）
- **采集**：开始/停止；「录制 CSV」选文件后边采边写，列和 CLI 的 log 一致
- **设置…**：C_REF_SEL / C_AVRG / CONV_TIME / 片内外补偿 / 端口掩码
- **标定…**：填已知电容和通道，可选扫描全部 31 档；结果存文件，下次自动加载
- **健康检查**：STATUS_0/1/2 解码打到日志里
- **时间窗 / 纵轴**：自动 / **去均值（看变化，标定后单位是 fF）** / 手动范围
- 右侧每通道一张卡：大字读数、比值、σ（fF 和 ppm）、min/max、显示开关
- 底部状态栏：速率（实测）、样本数、芯片当前配置、最近错误

模拟器的标定结果存到 `pcap04_calibration_sim.json`，**不会覆盖**真板子的标定文件。

线程模型：一个工作线程独占串口，界面只投递命令、从队列取事件。
采集途中切模式/改档位，工作线程先停流、执行、再续流，不会出现两处同时用串口。

---

## 9. USB 控制台（v3.1.0 新增）

以前控制台走 UART，是因为固件里没有 USB 设备栈 —— 烧录用的 DFU 是芯片内部
ROM bootloader 自带的，跟应用固件无关。现在固件自己实现了 USB CDC-ACM。

**硬件早就支持**：CC1/CC2 有 5.1k 下拉（规范的 Type-C 受电端），D+/D- 经
USBLC6-2 直连 PA11/PA12 这两个专用引脚（不需要 SYSCFG 重映射）。板上没有晶振，
所以 USB 时钟用 HSI48 + CRS，靠主机的 SOF 包把内部 48 MHz 校准到 USB 要求的精度 ——
ROM bootloader 本来就这么跑，这条路在这块板子上早已验证过。

### 实测速率提升

`rate.py` 扫描芯片自身的触发周期，看链路实际能跑多快：

```
C_AVRG   CONV_T    标称/Hz   实测/Hz     sd/ppm     ch2/pF
    32     2000      12.8      12.9      156.3   100.0085
    32      800      31.9      32.6      181.0   100.0079
    16      400      63.8      64.4      233.3   100.0072
     8      200     127.5     115.8      409.4   100.0028
```

**从 12.8 Hz 提到 116 Hz，约 9 倍。** 原来的天花板是 UART：一帧约 90 字节，
115200 baud 下每秒最多约 128 帧，加上一问一答的往返，实际卡在 12.8 Hz。
USB 全速 12 Mbit/s 之后瓶颈回到芯片本身。

再往上（标称 255 Hz 以上）固件的取帧循环跟不上就取不到样本了 ——
每帧要做 8 次 SPI 结果读取加文本格式化，帧周期 4 ms 时来不及。
116 Hz 对电容传感来说已经远超需要，没有继续追。

注意读数在 9 倍速率变化下保持 100.007 ± 0.005 pF，噪声按预期随速率上升
（平均次数变少）。

### 诊断

```bash
./pcap.py console usb
```

```
  state      : configured
  host port  : open (DTR asserted)
  bus resets : 2
  tx dropped : 0 bytes
```

`tx dropped` 不为零说明主机没在读、固件的发送缓冲满了。**控制台永远不会因此阻塞** ——
满了就丢字节，否则一个关掉的终端就能冻住正在进行的测量。

### 踩过的一个坑

第一版烧进去之后 USB 枚举正常、命令也能跑，但**打开串口要 50 秒**，而且每次都是
50 秒左右这么稳定 —— 这种"稳定的长延时"是超时重试的特征，不是拥塞。

原因：`SET_LINE_CODING` 是一个带数据阶段的主机→设备控制传输，三个阶段
SETUP → OUT 数据 → 我们回一个零长度 IN 作为状态阶段。第一版收了数据就重新
布防接收端点，**从没发那个状态包**。主机不会报错，只会重试到超时。
macOS 打开 tty 时正好会发这条命令，所以症状就是开口要 50 秒。

补上状态阶段之后，**打开时间从 52 s 变成 0.017 s**。

（这个症状和之前 Debug Probe 那个 hub 卡死长得一模一样，所以 `pcap04.py` 里
现在会区分：慢的是板子自己的口就提示查固件版本，是 probe 的口才提示拔插。）

### 逃生通道仍然有效

`dfu` 命令跳 ROM bootloader 之前会先 `usb_cdc_detach()`：清 DPPU 让主机看到拔出、
关掉 USB 外设和时钟。不做这一步的话 ROM 的 USB 初始化会遇到一条"已经挂着设备"的总线，
DFU 枚举可能失败 —— 那会同时废掉 `dfu` 命令和双击 RESET 的逃生通道，也就是所有回到板子的路。
实测烧录两次都正常。

UART 控制台保持并行工作，就是为了万一 USB 出问题还能进去。

---

## 10. 量程

芯片返回的是 **比值** `ratio = C / Cref`，Q5.27 格式（5 位整数 + 27 位小数），
所以满量程恒等于 **32 × Cref**，LSB 恒等于 **Cref / 2²⁷**。两端都跟着 C_REF_SEL 走。

本板实测（用 CTEST1 上的 100 pF 标定出的 Cref）：

| C_REF_SEL | Cref 实测 | 满量程 | LSB |
|---|---|---|---|
| 2  | 12.04 pF | 385 pF | 0.09 aF |
| 4  | 14.24 pF | 456 pF | 0.11 aF |
| 8  | 18.62 pF | 596 pF | 0.14 aF |
| 16 | 27.19 pF | 870 pF | 0.20 aF |
| 24 | 34.97 pF | 1119 pF | 0.26 aF |
| 31 | 40.14 pF | **1285 pF** | 0.30 aF |

**用片内参考时，量程上限约 1285 pF**（C_REF_SEL=31）。手册标称的
"1pF 到 100nF" 需要**外部参考电容** —— 手册自己也写了"Internal reference 1pF to 31pF"。

要超过 1285 pF 就得设 `C_REF_INT=0` 用外部参考，参考电容接在 **PC0/PC1**，
代价是浮空通道从 3 个变成 2 个（PC2/PC3 和 PC4/PC5）。

下限不是由 LSB（亚阿法）决定的，而是由噪声：默认配置下约 13 fF RMS（见第 5 节），
提高 C_AVRG 可以压到 4 fF 左右。另外接地模式下每个电极自带 12–17 pF 走线电容做底，
浮空模式下那 22 pF 走线寄生会被片外补偿扣掉。

---

## 11. 接真实传感器：DISCHARGE_TIME 这个坑

**症状**：把液位计接到 PC2/PC3，通道读数钉死在满量程，`health` 显示
`STATUS_2 = 0x0C → PortErr(PC2), PortErr(PC3)`。同一块板子上 PC4/PC5 的
100 pF C0G 一切正常。

**不是量程问题**：探头约 70 pF（实测含线缆 96 pF），满量程 1285 pF；
而且把 C_REF_SEL 从 31 一路降到 8，读数纹丝不动仍是 32.000000 —— 真的超量程的话
换参考档位读数会变。

**原因**：ScioSense 标准配置里 **DISCHARGE_TIME = 0**。手册对 C_PortError 的解释是
"短路到地、**放电电阻太大**、电容太大、或者预充/满充/放电时间设置不当"。
零放电时间对付一颗短走线上的 C0G 没问题，但真实探头带线缆、带有损介质，
零时间放不完电，端口就报错、结果钉在满量程 —— 看起来就像"这个通道坏了"。

**实测**：

```
DISCHARGE_TIME   速率      ch1(探头)   ch2(100pF)   状态
      0         12.85 Hz   1284.5 pF    99.55 pF   PortErr PC2,PC3   ← 钉在满量程
      2         12.86 Hz     96.61 pF   99.73 pF   ok
      8         12.86 Hz     96.59 pF   99.97 pF   ok
     10          6.46 Hz     96.31 pF   99.99 pF   ok   ← 转换塞不进一个触发周期，速率减半
```

**固件 v3.2.0 起默认 DISCHARGE_TIME = 8** —— 清错误有余量，且不损失速率。
需要调的话：

```bash
./pcap.py config --disch 16      # 或 ./pcap.py console "disch 16"
```

超过 8 之后转换时间塞不进一个触发周期，速率会减半，`params` 和 `speed` 都会显示实测速率。

**探头本身的噪声比标准电容大得多**：默认配置下 ch1 约 3800 ppm（364 fF），
而同一时刻 ch2 只有 129 ppm（12.9 fF）。把 C_AVRG 提到 256 之后 ch1 降到
1260 ppm（121 fF），ch2 降到 43 ppm。探头是有损器件、又挂着线缆，这个差距是真实的，
不是配置问题 —— 要更低的噪声就得在探头和线缆上想办法（缩短线缆、加屏蔽）。

---

## 12. 上下电 / 重连的逻辑（v3.3.0 修复）

**症状**：`power off` 再 `power on` 之后，`params` 仍然说
"firmware in PCAP04 SRAM : loaded"，`read()` 也照样返回一组看起来很正常的读数 ——
但那是**上一次的旧值**。

**根因**：固件里的 `g_loaded` 标志只在 `load` 时置 1，从来没有被清零过。
掉电把 PCAP04 的 SRAM 和配置寄存器全清了，标志却还留着；主机端的
`_ensure_loaded()` 信了这个标志，就不会重新加载。

更糟的是 **POR 只清配置寄存器，不清结果寄存器** —— 芯片已经死了，
`resd` 却还能读回上一次的转换结果。数据看着完全合理，实际是陈旧的。
这是最难发现的一类故障。

**修复**：

- `rail on` / `rail off` / `safe_shutdown` 都会清 `g_loaded`
- 新增 `pcap_loaded_now()`：不光看标志，还要**问芯片自己** —— 读 cfg 0x2F 的 RUNBIT。
  POR 之后 RUNBIT 必然是 0。这样连"看门狗自己把芯片复位了"也能抓到
- `params` 里芯片空白时不再从清零的 cfg 0x04 推断模式（那会让主机悄悄切成 6 通道接地解读），
  改为显示"intended; chip is blank"
- `resd` 发现 RUNBIT 清零时明确警告结果是陈旧的
- 主机端 `read()` 遇到 RUNBIT 清零直接抛异常，不再返回旧值（要看可以传 `allow_stale=True`）；
  `collect()` / `stream()` 会自动重新加载

修复后的实测：

```
2. rail off, rail on, then a plain read (no --reload):
   params loaded=False  mode=FLOATING          ← 不再误报
   read() correctly refused: the PCAP04 has been reset ...
3. does collect()/stream() recover by itself?
   collect() -> [0.138, 642.238, 99.979]  (auto-reloaded)   ← 自动恢复
```

### 顺带修掉一个我自己引入的回归

第一版修复把 `pcap_loaded_now()` 直接放进了 `cmd_results()` 的开头。
那多出一次配置读，也就多一个 SSN 上升沿；标准配置里 `EN_ASYNC_RD` 是开的，
芯片会把"上一个值已被读走"当成可以更新结果寄存器的信号，于是我们读到一半它就改了。
实测 `resd` 路径上 ch0 在 0.128 → 0.276 pF 之间跳，而 INTN 门控的 `stream` 路径纹丝不动。

改成用 `cmd_results` 本来就要读的 STATUS_0 里的 RUNBIT 位，不额外发 SPI 事务。
修复后两条路径读数一致（0.130 pF 稳定）。

**教训：测量路径上不要插入额外的 SPI 事务。**

---

## 13. 液位计要用接地模式，不是悬浮模式

接地模式下逐个电极测出来：

```
   PC0 J2      13.548 pF     （空，基线 12.81）
   PC1 J3     363.989 pF     ← 液位计在这里
   PC2 J4      18.168 pF     （空，基线 17.45）
   PC3 J5      14.499 pF     （空，基线 13.78）
   PC4 J6     135.256 pF     （CTEST1 的 100 pF）
   PC5 J7     138.053 pF
```

**液位计是对地的单端传感器**（探头对罐壁/地），不是浮空传感器。

在**悬浮模式**下 ch0 测的是 PC0 和 PC1 **之间**的差分电容，而且片外补偿
（`C_COMP_EXT`）恰恰会把每个节点**对地**的电容扣掉 —— 而对地电容正是液位计的信号本身。
所以悬浮模式下 ch0 只读到 0.130 pF，看起来像"没接"。

**接地模式下同一个探头读 364 pF，噪声 sd 0.013 pF（36 ppm）** —— 比它挂在悬浮通道上时的
3800 ppm 好两个数量级。单端探头就该用单端模式测。

```bash
./pcap.py -m g read          # 六个电极分别对地
```

364 pF 也在量程内（片内参考 N=31 时满量程 1285 pF）。

**判断依据**：如果传感器的一端接的是地/罐体/机壳，那就是接地型，用 `-m g`；
只有两端都悬空（比如跨在 CTEST1 上的那颗 100 pF）才是浮空型，用 `-m f`。

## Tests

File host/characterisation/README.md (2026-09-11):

# Characterisation scripts

These reproduce the numbers in `../../docs/measurements.md`. They are
measurement sweeps rather than polished tools — read them before running them,
since several deliberately push the chip outside its default configuration.

| Script | What it measures |
|---|---|
| `calib.py` | Cref against a known capacitor across all C_REF_SEL codes; also the external-compensation offset |
| `range.py` | full scale and LSB per reference setting |
| `avrg.py` | noise versus averaging depth, and the C_AVRG >= 512 anomaly |
| `disch.py` | the DISCHARGE_TIME threshold for a real sensor |
| `rate.py` | achieved sample rate versus the chip's trigger period |
| `session.py` | minimal prompt-framed console session, used by the others |

Each expects a board with a known capacitor fitted. `calib.py` and `range.py`
assume 100 pF on channel 2 (`CTEST1`); change `KNOWN`/`CNOM` at the top if
yours differs.

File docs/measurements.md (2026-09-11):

# Measured results

Everything here was measured on one assembled v1.5 board. The scripts that
produced each number are in `host/characterisation/`. Where a figure disagrees
with the datasheet, the disagreement is stated rather than smoothed over.

Reference capacitor for all calibration: a 100 pF part fitted to `CTEST1`,
which bridges PC4/PC5 (floating channel 2). Its own tolerance sets the absolute
scale of everything below; the *shape* results (linearity, ratios) do not
depend on it.

---

## 1. On-chip reference capacitor

`range.py` / `calib.py --sweep`. The chip returns `ratio = C / Cref` in Q5.27,
so full scale is `32 × Cref` and the LSB is `Cref / 2²⁷`.

| C_REF_SEL | Cref measured | Full scale | LSB |
|---:|---:|---:|---:|
| 1 | 10.89 pF | 348 pF | 0.08 aF |
| 2 | 12.04 pF | 385 pF | 0.09 aF |
| 3 | 12.42 pF | 397 pF | 0.09 aF |
| 4 | 14.24 pF | 456 pF | 0.11 aF |
| 6 | 15.70 pF | 502 pF | 0.12 aF |
| 8 | 18.62 pF | 596 pF | 0.14 aF |
| 9 | 18.95 pF | 606 pF | 0.14 aF |
| 12 | 22.14 pF | 708 pF | 0.16 aF |
| 16 | 27.07 pF | 866 pF | 0.20 aF |
| 20 | 30.65 pF | 981 pF | 0.23 aF |
| 24 | 34.82 pF | 1114 pF | 0.26 aF |
| 28 | 38.33 pF | 1227 pF | 0.29 aF |
| 31 | 40.14 pF | **1285 pF** | 0.30 aF |

Fit: mean step **0.975 pF/code** (datasheet 0.959, +1.7 %), extrapolated
intercept **9.91 pF** (datasheet 3.23 pF, **+6.7 pF**).

The residual against an affine model is ±4 %, and the residual pattern is
*identical* between the compensation-on and compensation-off sweeps — so this
is the reference bank's real differential nonlinearity, not measurement noise.
The datasheet does say "Note: Step width varies."

**Consequence: calibrate at the code you use.** Do not interpolate, and do not
use the datasheet formula.

Going above 1285 pF requires an external reference capacitor (`C_REF_INT = 0`,
reference on PC0/PC1), which costs one floating channel.

## 2. External compensation = trace capacitance to ground

Measuring the same channel with `C_COMP_EXT` on and off, at ten different
reference settings:

```
ratio(off) / ratio(on) = 1.221370 ± 1.09e-4   (89 ppm)
```

Constant to 89 ppm while Cref varies 3.7:1. That simultaneously confirms the
`ratio = C/Cref` model and that compensation removes a *fixed* capacitance:

```
PC4/PC5 trace capacitance to ground = 22.14 pF
```

## 3. Electrode trace capacitance

Grounded mode, each electrode against ground, bare board:

```
PC0 12.81   PC1 13.94   PC2 17.45   PC3 13.78   PC4 132.36*  PC5 134.82*   pF
```

\* PC4/PC5 elevated by the 100 pF fitted on CTEST1 between them.

Fitting the bare electrodes against trace length gives

```
C = 4.18 pF + 0.158 pF/mm
```

Five of six electrodes fit within ±3 %. The one outlier, PC4 at −20 %, is
exactly the electrode the design review had flagged for being routed on L4
under the chassis pour instead of over the ground plane — the layout objection
was independently confirmed by measurement.

## 4. Noise

Referred to a 100 pF sensor. `avrg.py`.

| C_AVRG | CONV_TIME | rate | sd/mean | rms noise |
|---:|---:|---:|---:|---:|
| 32 | 2000 | 12.8 Hz | 194 ppm | 20.0 fF |
| 64 | 2000 | 12.8 Hz | 142 ppm | 14.7 fF |
| 128 | 2000 | 12.9 Hz | 62 ppm | 6.4 fF |
| 255 | 2000 | 6.9 Hz | 60 ppm | 6.2 fF |
| 256 | 8000 | 3.3 Hz | 38 ppm | 3.9 fF |

Roughly 1/√N, as expected.

The datasheet quotes 19 aF at 10 Hz (floating, fully compensated, 10 pF base).
This board is ~250× above that. Known contributors: the sensor is 10× larger,
the SPI bus is being polled *during* conversion (the datasheet explicitly warns
"Traffic on interface may enhance noise"), the precharge/discharge times are
ScioSense defaults tuned for ~10 pF, the reference (41 pF) is not matched to the
sensor (100 pF), and the part under test is an ordinary ceramic rather than a
C0G on an evaluation board.

### C_AVRG ceiling

| C_AVRG | reading |
|---:|---|
| ≤ 257 | ratio 2.4911 → 102.9 pF |
| ≥ 512 | ratio 2.0042 → 82.8 pF (**19.5 % low**) |

256 and 257 both read correctly, so this is not a zero-low-byte bug. Most
plausible cause is accumulator saturation with large capacitances. Firmware and
host both clamp at 256.

## 5. DISCHARGE_TIME

The ScioSense reference configuration ships `DISCHARGE_TIME = 0`. With a real
probe (~96 pF including cable) on PC2/PC3:

| DISCHARGE_TIME | rate | probe | 100 pF reference | status |
|---:|---:|---:|---:|---|
| 0 | 12.85 Hz | 1284.5 pF | 99.55 pF | `PortErr PC2,PC3` — pinned at full scale |
| 2 | 12.86 Hz | 96.61 pF | 99.73 pF | ok |
| 8 | 12.86 Hz | 96.59 pF | 99.97 pF | ok |
| 10 | 6.46 Hz | 96.31 pF | 99.99 pF | ok, but the conversion no longer fits one trigger period |

The datasheet lists the causes of `C_PortError` as: short to ground, discharge
resistivity too big, capacitance too big, or an ill-defined
precharge/fullcharge/discharge time. With a known-good 100 pF reading correctly
on the adjacent channel, and the fault persisting across every C_REF_SEL
setting, only the timing explanation survives.

Firmware ≥ 3.2.0 defaults to 8: clear margin, no rate cost.

## 6. Sample rate over USB

`rate.py`. Before firmware 3.1.0 the console was a UART behind a debug probe
and topped out near 12.8 Hz — a ~90-byte frame at 115200 baud plus the
request/response round trip. With the board's own USB CDC console the console
stops being the limit:

| CONV_TIME | nominal | achieved | ch2 |
|---:|---:|---:|---:|
| 2000 | 12.8 Hz | 12.9 Hz | 100.0085 pF |
| 800 | 31.9 Hz | 32.6 Hz | 100.0079 pF |
| 400 | 63.8 Hz | 64.4 Hz | 100.0072 pF |
| 200 | 127.5 Hz | 115.8 Hz | 100.0028 pF |

**9× improvement.** Above this the firmware's frame loop cannot keep up — each
frame does eight SPI result reads plus text formatting, and the period is 4 ms.

The reading holds at 100.007 ± 0.005 pF across a 9× rate change.

## 7. Power sequencing

- +3V3P rises to 3.297 V in **4 ms** after the U5 load switch is enabled
- discharge to below 50 mV takes **~43 ms** (RQOD1 470 Ω plus the switch's own
  25 Ω into 20 µF) — matching the design review's prediction
- the PCAP04's SRAM firmware does not survive this, so a reload is required
  after every power cycle

## 8. Watchdog

`WD_DIS` (cfg 0x1C) = 0x5A is effective: the chip holds `RUNBIT` for at least
50 s of complete SPI silence. A blank chip that has never been loaded, however,
triggers its own watchdog POR roughly every 10 s, and `POR_FLAG_WDOG` then
survives as a sticky flag into a subsequently healthy session — so treat that
flag as history, not as a live fault.

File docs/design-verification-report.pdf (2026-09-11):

## A Three-Channel Floating-Electrode Capacitance Readout Board Based on the PCAP04 Capacitance-to-Digital Converter

Design Description, Independent Verification and Review of Hardware Revision v1.5

Jana Baker

September 2026

Abstract

This document describes and verifies a compact acquisition board for three cable-connected capacitive sensors (nominally 64–256 pF each) used for capacitive level and position sensing. The board combines a ScioSense PCAP04 capacitance-to-digital converter (CDC), operated in floating mode with full internal and external parasitic compensation, with an STM32G0B1 microcontroller that provides the SPI host, a USB 2.0 full-speed CDC link and an explicit powergating and tri-state interlock for the analogue section. The six sensor electrodes enter through edge-mounted SMA connectors; supply rails are derived from USB or an external 5 V input through separate digital and ultra-low-noise analogue regulators. The verification reported here was performed independently of the CAD tool: the schematic and board files (KiCad 10) were parsed programmatically, the resulting pin–net map was cross-checked against the manufacturers’ datasheets for all seven integrated circuits, and the copper geometry was analysed for signal-integrity and manufacturability. All 109 IC pin assignments were found to be correct and the board passes native ERC/DRC with zero violations. Eleven observations are reported, none of which prevents fabrication of the bare board; the most significant concern is the routing of signal tracks through the internal ground-plane layer, which contradicts the design’s own layout requirement. Recommended corrections for a v1.6 revision and a bring-up procedure are given.

### Contents

1 Introduction | 3
2 Measurement principle | 3
3 System architecture | 5
4 Circuit design | 6

PCAP04 three-channel capacitance readout board – design and verification | v1.5 / C496550
5 Printed-circuit-board layout | 10
6 Verification | 13
7 Findings and recommendations | 14
8 Bring-up and operating procedure | 16
9 Conclusion | 17
A Bill of materials | 18
B Net list summary | 19

### 1 Introduction

Capacitive sensing offers a simple, drift-tolerant way of measuring the level of a dielectric liquid or the relative position of two conductors: the capacitance between a pair of electrodes changes with the fraction of the gap filled by the medium or with the electrode overlap. In instrumentation the electrodes are frequently remote from the electronics and are reached through coaxial cables, so that the readout must tolerate a cable capacitance to ground that is comparable to, or larger than, the quantity being measured.
The PCAP04 [1] is a single-chip capacitance-to-digital converter that measures capacitance ratiometrically by timing the discharge of an RC network. It supports up to six grounded or three floating capacitors, provides on-chip compensation of internal and external parasitic capacitance, and reports a resolution in the attofarad range at low data rates. These properties make it a natural choice for a small, cable-driven, multi-channel level sensor front end.
This document has two purposes. First, it gives a complete engineering description of the hardware revision v1.5 of the PCAP04 Acquisition 3CH board (100 × 100 mm, four copper layers), including the measurement principle, the circuit design rationale, and the printed-circuit-board (PCB) layout. Second, it reports an independent correctness review of that design. The review was deliberately carried out outside the CAD environment: the KiCad schematic and board files were parsed with purpose-written scripts to recover the pin–net connectivity and copper geometry, and every integrated-circuit pin was compared against the manufacturer’s datasheet. Design rules, decoupling, power sequencing, the analogue front end and the layout were then assessed against the datasheet requirements and against the design intent stated in the schematic notes. Section 2 summarises the measurement principle, Sections 3–5 describe the design, Section 6 the verification method and results, and Section 7 the findings and the recommendations for the next revision.

### 2 Measurement principle

### 2.1 Ratiometric discharge-time measurement

The PCAP04 charges the capacitor under test and then discharges it through an on-chip resistor R while a time-to-digital converter measures the interval until the port voltage crosses a fixed comparator threshold. For a capacitor C the discharge is exponential, so that the measured interval is
τ = k R C, k = ln
V0

Vth
, | (1)

where V0 is the pre-charge voltage (the 1.8 V core supply) and Vth the comparator threshold. The same resistor is used for a reference capacitor Cref, so that the unknown constants k and R cancel in the ratio delivered by the on-chip DSP:

τN

τref

=

CN

Cref

. | (2)

Figure 1 illustrates the timing. The internal discharge resistor can be set to 10 kΩ, 30 kΩ, 90 kΩ or 180 kΩ separately for ports PC0–PC3 (with the internal reference PC6) and for ports PC4–PC5 [1]. With the default 30 kΩ and the largest sensor value of 256 pF the time constant is RC ≈ 7.7 µs; including 150 pF of cable capacitance at the discharging node it rises to about 12 µs, well within the discharge-time range of the converter.

### 2.2 Floating sensors and parasitic compensation

Two connection schemes are available. In grounded mode one electrode of each sensor is tied to ground and up to six sensors share the reference PC0; the full cable capacitance of the active

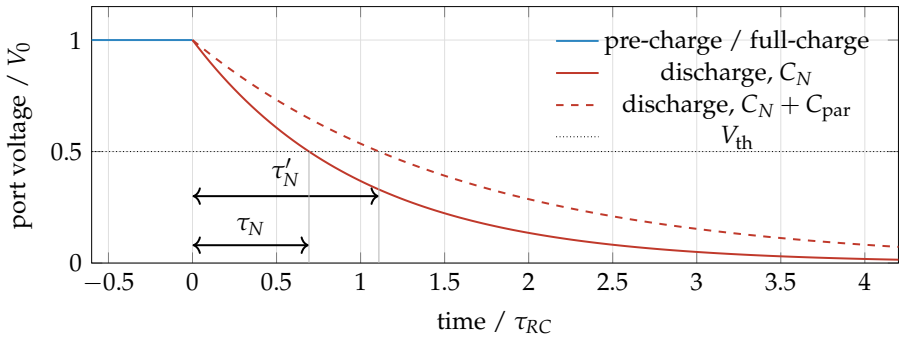
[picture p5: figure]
time / τRC; port voltage /; pre-charge / full-charge discharge, CN; discharge, CN; + Cpar; Vth

Figure 1: Discharge-time principle of the PCAP04. The interval from the start of the discharge to the comparator threshold crossing is proportional to R C. A parasitic capacitance to ground at the discharging node lengthens the interval (τ

′
N

); in floating mode this contribution is measured separately and removed (Section 2.2).

conductor then adds directly to the measured value. In floating mode each sensor is connected between two ports (PC0/PC1, PC2/PC3, PC4/PC5); only one electrode is charged while the other is switched to ground, and the parasitic capacitances of both conductors to ground can be separated from the sensor value [1]. This is the scheme adopted here (Figure 2). For each floating capacitor the converter performs three measurements: (i) electrode A charged, electrode B grounded, giving CAB + CpA + Cint; (ii) the mirror image, giving CAB + CpB + Cint; and (iii) both electrodes charged to the same potential, so that no field exists across the sensor and only CpA + CpB + Cint is seen. A fourth measurement with all ports open (internal compensation) yields Cint together with the comparator delay. From these the DSP firmware solves for CAB alone. The datasheet recommends grounding the cable shields at the PCB end, which is exactly the topology used on this board (Section 4.1).

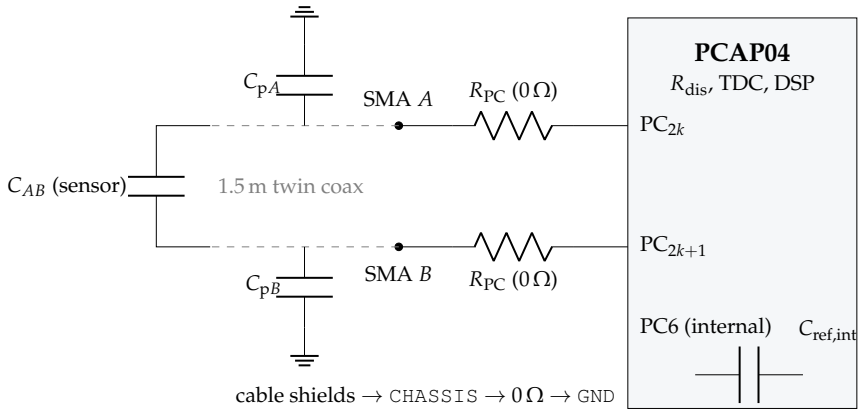
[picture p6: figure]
PCAP04; Rdis, TDC, DSP; PC6 (internal); Cref,int; RPC (0 Ω); SMA A; SMA B; 1.5 m twin coax; CpA; CpB; CAB (sensor); cable shields → CHASSIS → 0 Ω → GND

Figure 2: Floating connection of one sensor channel k ∈ {0, 1, 2}. The electrode pair is measured between two CDC ports; the coaxial shields are returned to the board ground at a single point. CpA and CpB (cable plus PCB trace) are removed by the external compensation sequence; the ratio is formed against the programmable internal reference capacitor on the internal port PC6.

### 2.3 Reference capacitor and dynamic range

Because all three port pairs are occupied by sensors, the design relies on the internal reference capacitor (register bit C_REF_INT), whose value is programmable as Cref,int ≈ 0.959 pF · N + 3.23 pF for N = 0 . . . 31, i.e. up to about 33 pF [1]. With the maximum setting the expected ratios lie between 64/33 ≈ 1.9 and 256/33 ≈ 7.8, which fits the 5-bit integer part of the result registers. Two consequences should be noted. First, the absolute accuracy of the readout is bounded by the tolerance and temperature drift of the on-chip reference, so a gain calibration against a known external capacitor is required for absolute measurements; the board provides a footprint (CTEST1, 100 pF C0G 0.1 %, not fitted) across PC4/PC5 for that purpose. Second, if the highest long-term stability is required, one port pair (PC0/PC1) can instead carry an external reference capacitor (C_REF_INT=0), at the cost of reducing the sensor count from three to two; the hardware supports both options without modification.

### 2.4 Resolution

The datasheet characterises the converter with a 10 pF base capacitance: in floating mode with full compensation the RMS noise is 8 aF at 2.5 Hz, 56 aF at 100 Hz and 156 aF at 1 kHz [1]. Since the discharge-time jitter is, to first order, a fixed fraction of the measured interval, the noise scales roughly with the total capacitance at the port; for the 64–256 pF sensors plus cable used here, a relative resolution in the 10⁻⁵
range at data rates of a few hertz can therefore be expected, corresponding to a few femtofarads. The dominant systematic effects are the reference drift discussed above and the temperature coefficient of the cable dielectric; the design keeps the electronics at room temperature and compensates the cable through the three-measurement sequence.

### 3 System architecture

Figure 3 shows the organisation of the board. Three functional regions are separated on the PCB and in the schematic: the sensor/chassis region with the six SMA inputs and the CDC, the real-time control region with the microcontroller and the SPI buffer, and the USB/power region. Table 1 lists the active components.

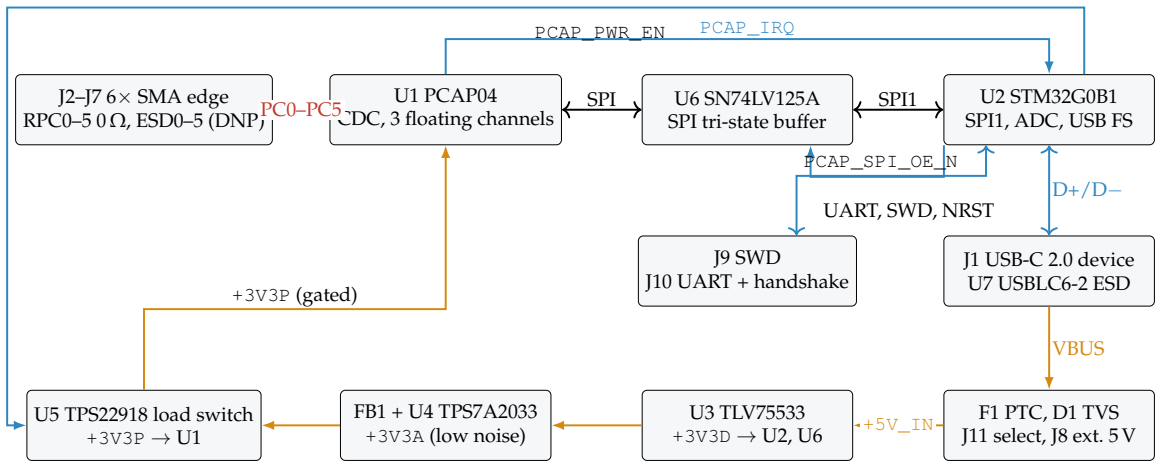
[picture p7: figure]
J2–J7 6× SMA edge RPC0–5 0 Ω, ESD0–5 (DNP); U1 PCAP04 CDC, 3 floating channels; U6 SN74LV125A SPI tri-state buffer; U2 STM32G0B1 SPI1, ADC, USB FS; J9 SWD J10 UART + handshake; J1 USB-C 2.0 device U7 USBLC6-2 ESD; F1 PTC, D1 TVS J11 select, J8 ext. 5 V; U3 TLV75533 +3V3D → U2, U6; FB1 + U4 TPS7A2033 +3V3A (low noise); U5 TPS22918 load switch +3V3P → U1; SPI; SPI1; PCAP_IRQ; UART, SWD, NRST; PCAP_SPI_OE_N; PCAP_PWR_EN; VBUS; +3V3P (gated)

Figure 3: Block diagram of the acquisition board. Red: analogue sense path; blue: digital control; orange: power. The CDC supply +3V3P is gated by the microcontroller, and the SPI lines are tri-stated while the CDC is unpowered.

Signal flow. Each SMA centre conductor reaches a CDC port through a 0 Ω series element (RPC0–RPC5) that reserves the option of a small series resistor, and has a not-fitted ESD-diode position to CHASSIS. The PCAP04 is read over a four-wire SPI bus. The bus does not connect to the microcontroller directly but through the quad buffer U6, whose output-enable lines are driven by the microcontroller and pulled inactive by default; this prevents the buffer outputs from back-feeding the CDC through its I/O protection diodes while its supply is switched off. The interrupt output of the CDC (PCAP_IRQ) goes to an EXTI-capable microcontroller pin through a

Table 1: Active components of revision v1.5.

Ref. | Part | Function | Package
U1 | ScioSense PCAP04-AQFM-24 | Capacitance-to-digital | con-
| | verter, SPI mode | QFN-24 4×4
U2 | ST STM32G0B1CBT6 | Cortex-M0+ host: SPI mas-
ter, ADC, USB 2.0 FS device,
| | UART | LQFP-48
U3 | TI TLV75533PDBVR | 3.3 V/500 mA LDO, digital rail +3V3D
SOT-23-5
U4 | TI TPS7A2033PDBVR | 3.3 V/300 mA ultra-low-noise LDO, analogue rail +3V3A
SOT-23-5
U5 | TI TPS22918DBVR | Load switch with slew control and quick output discharge, gated rail +3V3P
SOT-23-6
U6 | TI SN74LV125APWR | Quad tri-state buffer isolating the SPI bus | TSSOP-14
U7 | ST USBLC6-2SC6 | USB ESD protection | SOT-23-6
J2–J7 | BAT Wireless BWSMA-KE-P001 (LCSC C496550) Edge-mount SMA, 1.6 mm
| | PCB | edge clamp
J1 | HRO TYPE-C-31-M-12 | USB-C 2.0 receptacle, 16 pin | SMD/THT

1 kΩ series resistor. Two handshake lines (HOST_READY, MEAS_BUSY) and a UART are brought to header J10 for an external host; USB CDC over J1 is the primary data link.

Power domains. Three 3.3 V rails are used deliberately. +3V3D (U3) supplies the microcontroller and the SPI buffer; +3V3A (U4, preceded by ferrite bead FB1) is the low-noise analogue rail; +3V3P is +3V3A passed through the load switch U5 and supplies only the CDC. The microcontroller can thus power-cycle the CDC under firmware control (e.g. to recover from a latched state or to enforce a clean configuration sequence), and can verify through a resistive divider on ADC input PA0 (PCAP_PWR_SENSE) that the rail has actually collapsed before re-enabling it.

### 4 Circuit design

### 4.1 Sensor front end

Figure 4 shows one of the three identical channels together with the shared chassis network. The SMA outer conductors of all six connectors and the USB receptacle shell form the CHASSIS net, which is bonded to signal ground at exactly one point through the 0 Ω link RCH0. Alternative positions for a 1 MΩ bleed resistor (RCH1) and a 1 nF capacitor (CCH0) are provided but not fitted, so that the single-point bond can be replaced by a soft ground if the installation requires it. The schematic note explicitly prohibits a second chassis-to-ground connection. This arrangement satisfies the PCAP04 recommendation that cable shields be grounded at the PCB end [1], keeps the shield return currents away from the CDC ground pins, and defines the potential of the parasitic capacitances that are removed by the compensation sequence.
The series elements RPCn are fitted as 0 Ω. Any series resistance adds directly to the on-chip discharge resistor in Eq. (1); for the 30 kΩ setting a 100 Ω part would introduce a 0.3 % gain change that is common to sensor and (internal) reference only if the reference path has the same resistance, which it does not. Keeping them at 0 Ω is therefore the correct choice for accuracy; the footprints remain useful for a ferrite bead or a fusible link should EMI or fault tolerance require it. The ESD positions ESD0–ESD5 (SOD-882, to CHASSIS) are not fitted on the first build because any clamp diode adds a voltage-dependent capacitance and leakage in parallel with the sensor; they can be populated with a low-capacitance (< 0.5 pF) device if field experience shows a need.

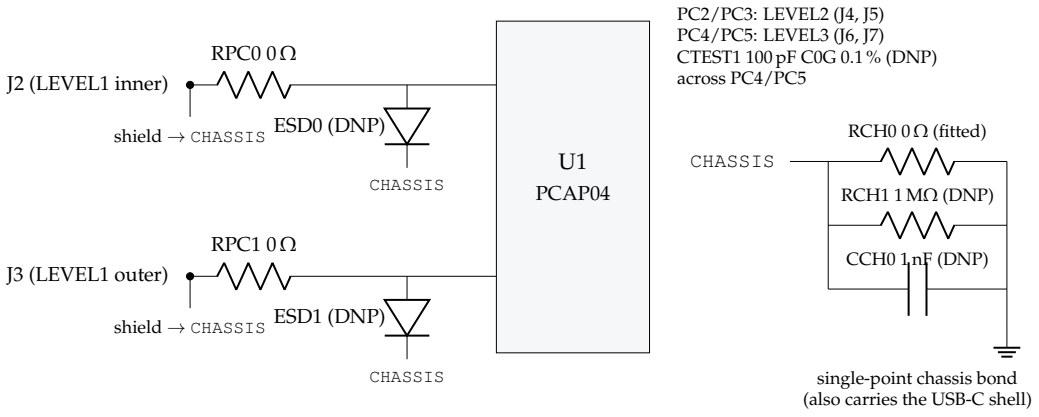
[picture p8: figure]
J2 (LEVEL1 inner); RPC0 0 Ω; ESD0 (DNP); CHASSIS; shield → CHASSIS; J3 (LEVEL1 outer); RPC1 0 Ω; ESD1 (DNP); PCAP04; PC2/PC3: LEVEL2 (J4, J5) PC4/PC5: LEVEL3 (J6, J7) CTEST1 100 pF C0G 0.1 % (DNP) across PC4/PC5; RCH0 0 Ω (fitted); RCH1 1 MΩ (DNP); CCH0 1 nF (DNP); single-point chassis bond (also carries the USB-C shell)

Figure 4: Sensor front end for channel 1 (PC0/PC1) and the shared chassis network. Channels 2 and 3 are identical.

### 4.2 CDC and its supplies

The PCAP04 is powered from the gated rail +3V3P on both VDD33 pins (4 and 14). The datasheet requires a buffer capacitor of at least 10 µF on VDD33 and at least 4.7 µF on the 1.8 V core-regulator output VDD18 [1]. The board fits 100 nF directly at each VDD33 pin (C1, C2, within 2 mm) plus two 10 µF bulk capacitors (C3, C7), and 4.7 µF (C4) at VDD18 with an optional 100 nF position (C5). VDD18 is a regulator output; the schematic warns that it must never be connected to +3V3P, and the netlist confirms that it is a private net (VDD18_LOCAL) with only the two capacitors attached. All four ground pins including the exposed pad are on GND. The interface select pin IIC_EN
(13) is tied hard to ground, selecting the SPI interface; the datasheet states that this pin must not float. The temperature-measurement ports PT0REF, PT1 and PTOUT and the auxiliary/guard port PCAUX are left open, as permitted when the resistance-to-digital function and guarding are unused (guarding is in any case not available in floating mode). The general-purpose ports PG2–PG4 are unconnected; PG5 carries the interrupt output once PG5_INTN_EN is set. A 100 kΩ pull-up (RCS_PU1) referenced to +3V3P holds the chip-select line inactive whenever the CDC is powered and the buffer is tri-stated.

### 4.3 SPI isolation and CDC power gating

Figure 5 shows the interlock between the two supply domains. The three host-to-CDC lines (SCK, MOSI, CS) pass through buffers 1–3 of U6, the CDC-to-host line MISO through buffer 4; all four output-enable pins are on PCAP_SPI_OE_N, pulled to +3V3D by ROEPU1 so that the bus is tri-stated at reset and whenever the microcontroller pin is high-impedance. Series resistors of 33 Ω on the three driven lines damp reflections and limit current in the event of contention. The SN74LV125A’s Ioff specification allows its outputs to sit on an unpowered node [6], so the buffer outputs may legitimately face the unpowered CDC.
The load switch U5 is controlled by PCAP_PWR_EN with a 100 kΩ pull-down (RENPD1), i.e. the CDC is off until firmware asserts the enable; the ON-pin threshold of 1 V is easily met by the 3.3 V GPIO [5]. The 1 nF slew capacitor CCT1 gives a specified rise time of about 1.7 ms at 3.3 V, so that the inrush into the 20 µF of CDC decoupling is limited to roughly 40 mA. The quick-outputdischarge pin QOD is returned to +3V3P through RQOD1 (470 Ω); with the internal pull-down of about 25 Ω the switched-off rail decays with τ ≈ 495 Ω × 20 µF ≈ 10 ms and reaches the 50 mV threshold defined in the schematic in about 40 ms. The rail is monitored through RPS1/RPS2

(330 kΩ/100 kΩ, 0.77 V at full rail) with a 10 nF C0G filter capacitor; the 77 kΩ source impedance requires a long ADC sampling time (or reliance on the filter capacitor as a charge reservoir), which is a firmware setting. The CDC interrupt line has a 10 kΩ pull-down so that it reads as a defined level while the CDC is unpowered.

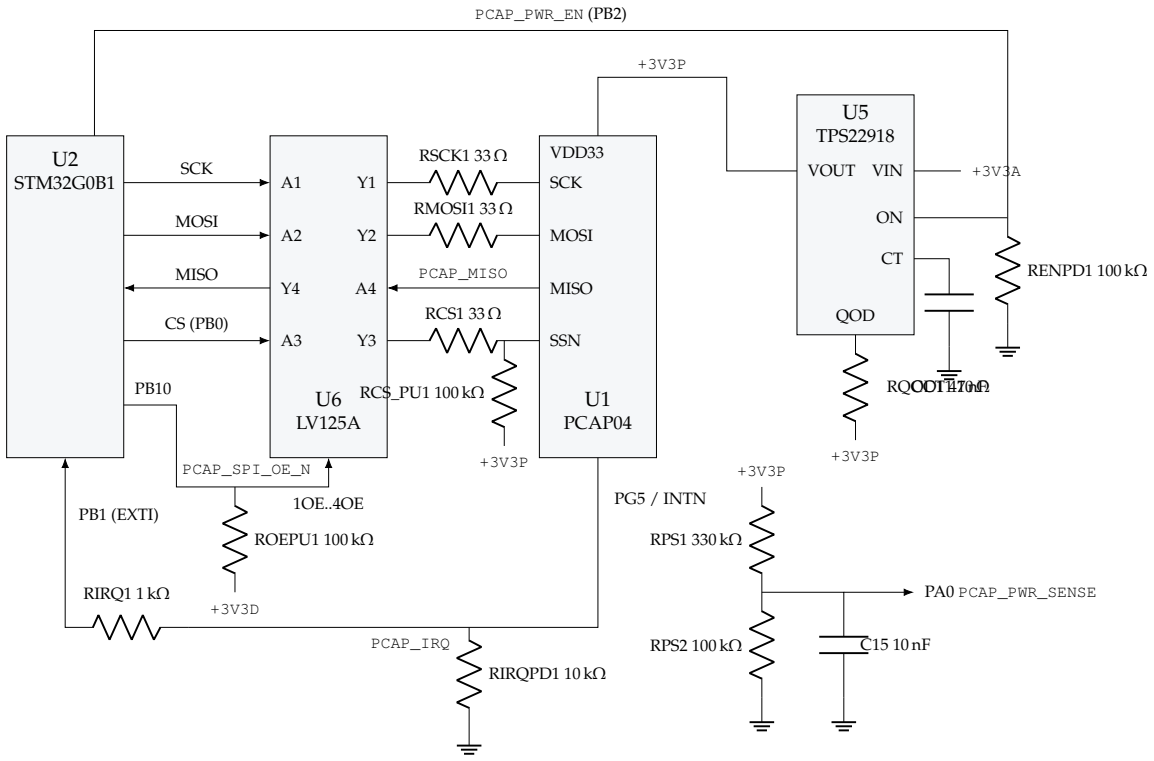
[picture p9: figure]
U2 STM32G0B1; U1 PCAP04; U5 TPS22918; SCK; RSCK1 33 Ω; MOSI; RMOSI1 33 Ω; RCS1 33 Ω; SSN; MISO; PCAP_MISO; RCS_PU1 100 kΩ; PCAP_SPI_OE_N; ROEPU1 100 kΩ; PG5 / INTN; RIRQ1 1 kΩ; PB1 (EXTI); PCAP_IRQ; RIRQPD1 10 kΩ; VOUT; VDD33; VIN; RENPD1 100 kΩ; PCAP_PWR_EN (PB2); CCT1 1 nF; RQOD1 470 Ω; QOD; RPS1 330 kΩ; RPS2 100 kΩ; PA0 PCAP_PWR_SENSE

Figure 5: SPI isolation and power gating of the CDC. The buffer outputs are enabled only while the CDC rail is up; the chip-select pull-up is referenced to the gated rail; the rail is switched with a controlled slew and actively discharged, and its state is read back by the ADC.

### 4.4 Microcontroller

The STM32G0B1CBT6 (LQFP-48, general-purpose variant) is chosen for its crystal-less USB full-speed device peripheral, which uses the internal 48 MHz oscillator trimmed by the clock-recovery system from the USB start-of-frame packets [2]. Accordingly no crystal is fitted: PF0/PF1 and PC14/PC15 are left open. All supply pins (VDD/VDDA, VREF+, VBAT) are tied to +3V3D, which the datasheet permits (VREF+ may equal VDDA; VBAT may be tied to VDD when no backup source exists). Decoupling is 100 nF on VDD/VDDA and VREF+ and 4.7 µF on VBAT (C8, C9, C10). NRST carries the recommended 100 nF capacitor, an additional 10 kΩ pull-up in parallel with the internal 25–55 kΩ pull-up, and the reset push-button SW1; the line is also available on the SWD header J9. SWCLK is shared with BOOT0 on PA14; no capacitor is placed on that pin so that debugging is unaffected, and boot-mode selection is left to the nBOOT_SEL option bit. Because a blank device automatically enters the system bootloader (flash empty check), first programming is possible over USB DFU without a debugger.
The pin usage is summarised in Table 2. SPI1 uses PA5/PA6/PA7 with PB0 as software chip-select, the CDC interrupt enters on PB1, the two control outputs are PB2 (power enable) and PB10 (buffer enable), PA0 is the ADC rail monitor, USART2 on PA2/PA3 and two GPIO handshake lines go to J10, and USB uses PA11/PA12. The remaining 25 I/O pins are unconnected and must be configured as pulled inputs or analogue in firmware.

Table 2: Microcontroller pin allocation (verified against the LQFP-48 pinout of [2]).

Pin | Port | Net | Role
4, 5, 6 | VBAT, VREF+, VDD/VDDA | +3V3D | supply
7 | VSS/VSSA | GND | ground
10 | PF2-NRST | NRST | reset (RC, button, SWD)
11 | PA0 | PCAP_PWR_SENSE | ADC, CDC rail monitor
13, 14 | PA2, PA3 | UART_TX, UART_RX | USART2 to J10
16, 17, 18 | PA5, PA6, PA7 | SPI1 SCK, MISO, MOSI | to/from U6
19 | PB0 | PCAP_CS | SPI chip-select (GPIO)
20 | PB1 | PCAP_IRQ (via 1 kΩ) | EXTI from CDC
21 | PB2 | PCAP_PWR_EN | load-switch ON
22 | PB10 | PCAP_SPI_OE_N | buffer output enable (active low)
23, 24 | PB11, PB12 | HOST_READY, MEAS_BUSY | handshake to J10
33, 34 | PA11, PA12 | USB_DM, USB_DP | USB FS device
35, 36 | PA13, PA14 | SWDIO, SWCLK_BOOT0 | SWD / BOOT0

### 4.5 USB interface and power input

The USB-C receptacle is wired as a legacy USB 2.0 upstream-facing port (Figure 6): CC1 and CC2 each carry a 5.1 kΩ pull-down (RCC1, RCC2) so that a Type-C source or a C-to-A cable supplies VBUS; both D+ and both D− contacts are paired; the SBU contacts are unconnected; the four VBUS contacts are joined. VBUS passes through a 500 mA PTC fuse F1 and is clamped by the SMF5.0A TVS D1 to form +5V_USB, which also powers the VBUS pin of the ESD array U7. The data lines pass through U7 (USBLC6-2SC6), whose two I/O pins per line are used as the “in” and “out” sides so that the clamp is in the signal path close to the connector. The connector shell is on CHASSIS. The 5 V source is selected with jumper J11 between +5V_USB and the external low-noise input J8 (+5V_EXT); the two sources are never paralleled. The selected +5V_IN feeds the digital LDO directly and the analogue LDO through the ferrite bead FB1 (600 Ω at 100 MHz); each LDO has its enable pin tied to its input and input/output capacitors that exceed the datasheet minima of 0.47 µF effective (TLV755P) and 1 µF (TPS7A20) [3, 4]. The TPS7A20 contributes 7 µVRMS of output noise and more than 60 dB of PSRR at 100 kHz, so that switching noise from a USB host supply is strongly attenuated before it reaches the CDC.

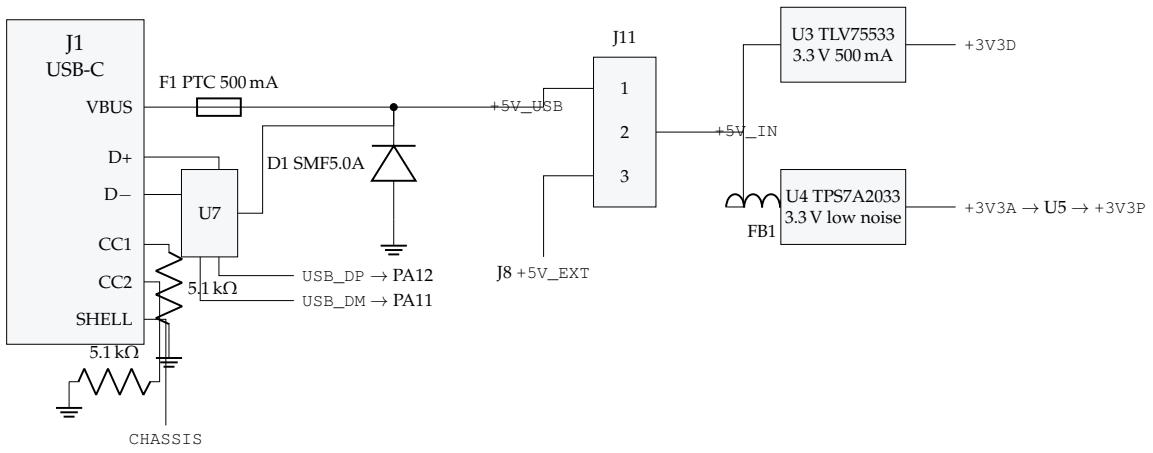
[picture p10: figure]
J1 USB-C; VBUS; SHELL; F1 PTC 500 mA; +5V_USB; D1 SMF5.0A; USB_DP → PA12 USB_DM → PA11 5.1 kΩ; CHASSIS; J8 +5V_EXT; U3 TLV75533; U4 TPS7A2033; 3.3 V low noise

Figure 6: USB-C input, protection, source selection and regulator tree. Decoupling capacitors are omitted for clarity (values in Appendix A).

### 5 Printed-circuit-board layout

### 5.1 Stack-up, outline and connectors

The board is a 100 × 100 mm, 1.6 mm four-layer FR-4 design with the layer functions listed in Table 3. No explicit stack-up is stored in the board file, so the fabricator’s default four-layer build applies; for the estimates below the common JLC04161H-7628 construction (0.21 mm prepreg between the outer layers and the adjacent planes, εr ≈ 4.4) is assumed. All six SMA connectors are on the left edge (x = 10 mm) at a pitch of 16 mm, arranged top to bottom as J4/J5 (channel 2), J2/J3 (channel 1) and J6/J7 (channel 3), so that the two electrodes of a channel are adjacent. USB-C, the external 5 V input, the UART, SWD and source-select headers are on the right edge. Figure 7 shows the copper of all four layers, rendered directly from the board file; Figure 8 shows the assembled top side.

Table 3: Layer assignment and principal copper statistics (from the KiCad board-statistics report and the geometry extraction of Section 6).

Layer | KiCad name | Function | Copper / routing content
L1 | F.Cu | components, | sense
lines, SPI, local power
| | | 577 mm² ; all six centre-pin lands
L2 | In1.Cu (GND_PLANE)
ground | reference
| | plane | solid pour, 92.0 % of area, one polygon; 494 mm of tracks embedded
L3 | In2.Cu (POWER_SIGNAL)
power | distribution,
| | signal escape | 292 mm of tracks, no pour
L4 | B.Cu | chassis pour under
SMA area, SMA bot-
| | tom lands | 2620 mm² , CHASSIS pour x < 35 mm

69 components (65 SMD, 4 THT); 275 SMD pads, 20 through-hole pads, 2 NPTH; 95 through vias (90×0.4 mm, 5×0.3 mm)
minimum track width 0.20 mm; minimum measured clearance 0.1516 mm (rule 0.15 mm); minimum drill 0.30 mm
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

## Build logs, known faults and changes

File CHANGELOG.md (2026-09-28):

# Changelog

Versions refer to the STM32 firmware; the host tools track it.

## Unreleased (host tools only)

- Fix: `pcap.py log` included the first, unsettled conversion in its summary
  statistics. One such sample inflated the reported sd from ~40 ppm to
  ~2500 ppm, and since `drift` was simply the last value minus the first, it
  also reported a drift of several tenths of a pF across a run that was in fact
  flat. The CSV still records every sample; only the statistics now skip the
  first two, matching what `PCap04.collect()` already did.

## 3.3.0

- Fix: the "PCAP04 firmware is loaded" flag was never cleared, so after a power
  cycle the board still reported `loaded` while every config register read 0.
  Because a PCAP04 power-on reset zeroes the config registers but *leaves the
  result registers holding the previous conversion*, a dead chip returned
  plausible-looking stale data. `rail on`/`rail off`/`safe_shutdown` now clear
  it, and the state is verified against the chip's own `RUNBIT` rather than
  trusted from a cached flag — which also catches a watchdog reset.
- Fix: `params` no longer infers the mode from a zeroed config register on a
  blank chip (it used to silently report GROUNDED and switch the host to a
  six-channel interpretation of nothing).
- Host `read()` raises on `RUNBIT` clear instead of returning stale values;
  `collect()`/`stream()` reload automatically.
- Fix: a regression introduced while making the above change — the verification
  read was placed at the start of `cmd_results()`, and that extra SSN edge makes
  the chip treat the previous value as consumed (`EN_ASYNC_RD` is on in the
  standard config), so the result registers could update mid-read. Now uses the
  `RUNBIT` bit in `STATUS_0`, which that command already reads.

## 3.2.0

- `DISCHARGE_TIME` now defaults to 8 instead of the ScioSense reference value of
  0. Zero works for a C0G part on a short trace but makes any sensor with series
  resistance or a lossy dielectric report `C_PortError` and read full scale.
- New `disch` console command, `set_discharge()` in the library,
  `--disch` in the CLI; `params` reports the value.

## 3.1.0

- Bare-metal USB CDC-ACM console. One USB-C cable now carries power, console
  and firmware update; the debug probe is no longer needed. The UART console
  stays live in parallel as a fallback.
- Clocked from HSI48 trimmed by the CRS against USB SOF — no crystal on this
  board.
- Sample rate over the console rises from 12.8 Hz to 116 Hz measured.
- `usb_cdc_detach()` before the ROM bootloader jump, so DFU and the double-tap
  RESET escape hatch both keep working.
- Host tools select the board's own port by USB VID/PID instead of taking the
  first `usbmodem`.

## 3.0.0

- `stream`: continuous acquisition gated on the INTN pin, so every frame is a
  distinct conversion and polling can never silently re-read one.
- `mode g|f`: runtime grounded/floating switch (~30 ms) without re-uploading
  the PCAP04 firmware.
- Named parameter commands: `avrg`, `conv`, `refsel`, `comp`, `ports`.
- `params` and `health` decode the configuration and status registers.
- `C_AVRG` clamped to 256 — at 512 and above the reading goes 19.5 % low.

## 2.0.0

- ScioSense standard DSP firmware (548 bytes) and default configuration
  embedded and uploaded to the PCAP04's SRAM at start-up, since its NVRAM
  ships blank.
- First real capacitance measurements.

## 1.x

- Board bring-up: clocks, power sequencing, ADC, SPI, USB DFU flashing,
  diagnostic console, self-test.

## 2026-09-28 — Full runtime configuration controls

- Add 90 datasheet-defined user fields shared by GUI, CLI and Python API.
- Add charging-resistor, precharge and full-charge control; grouped editor and JSON snapshots.
- Stop before masked writes, verify each byte and full readback, reject stale edits, and remain stopped on failure.
- Preserve reserved/factory fields; exclude NVRAM operations. Existing MCU firmware supported.
- Add protocol fault-injection tests and native Tk simulator smoke test; physical hardware untested.

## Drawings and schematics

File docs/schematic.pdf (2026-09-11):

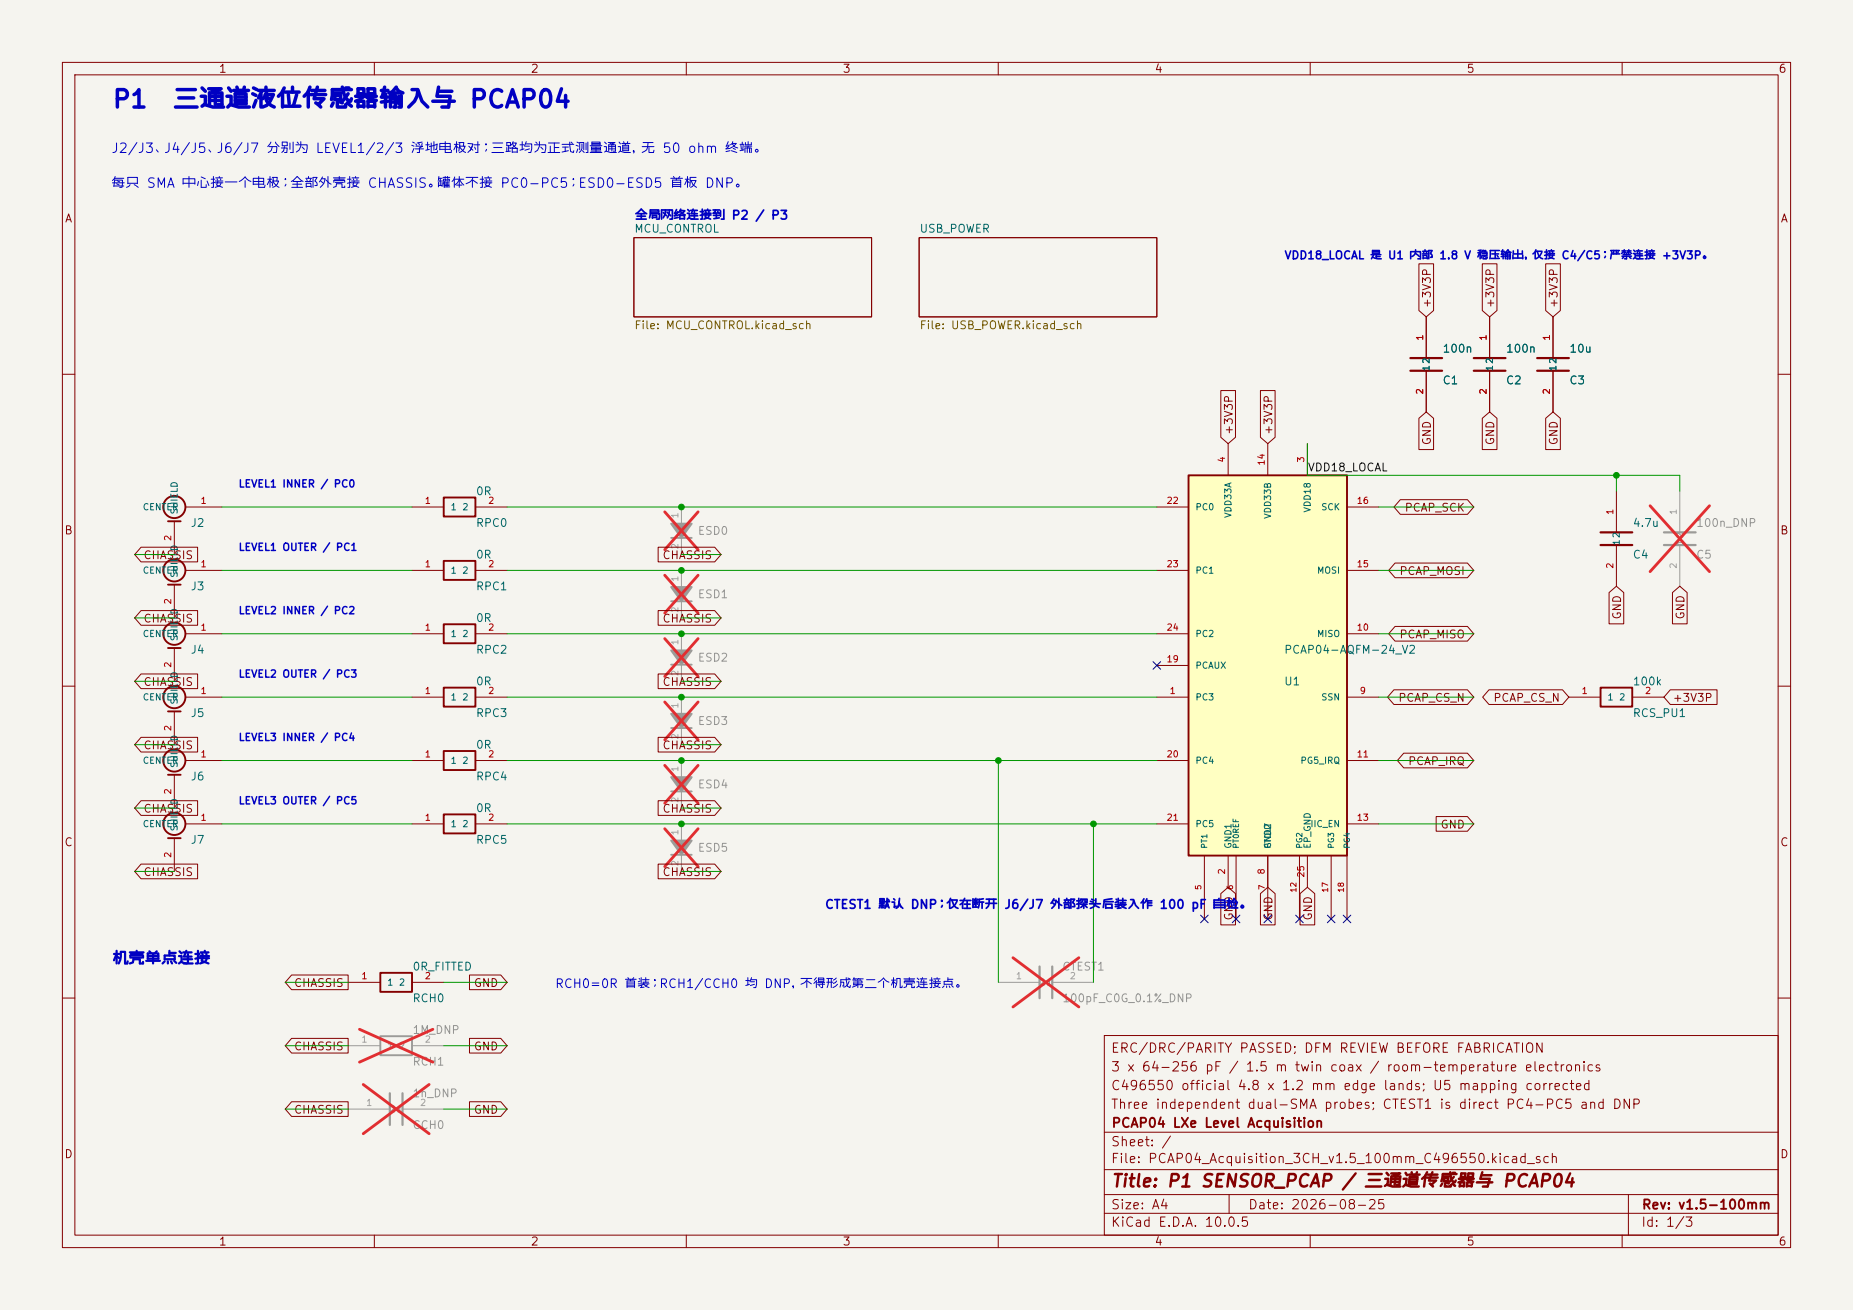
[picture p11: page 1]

J2/J3、J4/J5、J6/J7 分别为 LEVEL1/2/3 浮地电极对；三路均为正式测量通道，无 50 ohm 终端。

VDD18_LOCAL 是 U1 内部 1.8 V 稳压输出，仅接 C4/C5；严禁连接 +3V3P。 每只 SMA 中心接一个电极；全部外壳接 CHASSIS。罐体不接 PC0-PC5；ESD0-ESD5 首板 DNP。

ERC/DRC/PARITY PASSED; DFM REVIEW BEFORE FABRICATION
3 x 64-256 pF / 1.5 m twin coax / room-temperature electronics
C496550 official 4.8 x 1.2 mm edge lands; U5 mapping corrected
Three independent dual-SMA probes; CTEST1 is direct PC4-PC5 and DNP
PCAP04 LXe Level Acquisition
Sheet: /
File: PCAP04_Acquisition_3CH_v1.5_100mm_C496550.kicad_sch
Title: P1 SENSOR_PCAP / 三通道传感器与 PCAP04

Size: A4 | Rev: v1.5-100mm
KiCad E.D.A. 10.0.5 | Id: 1/3

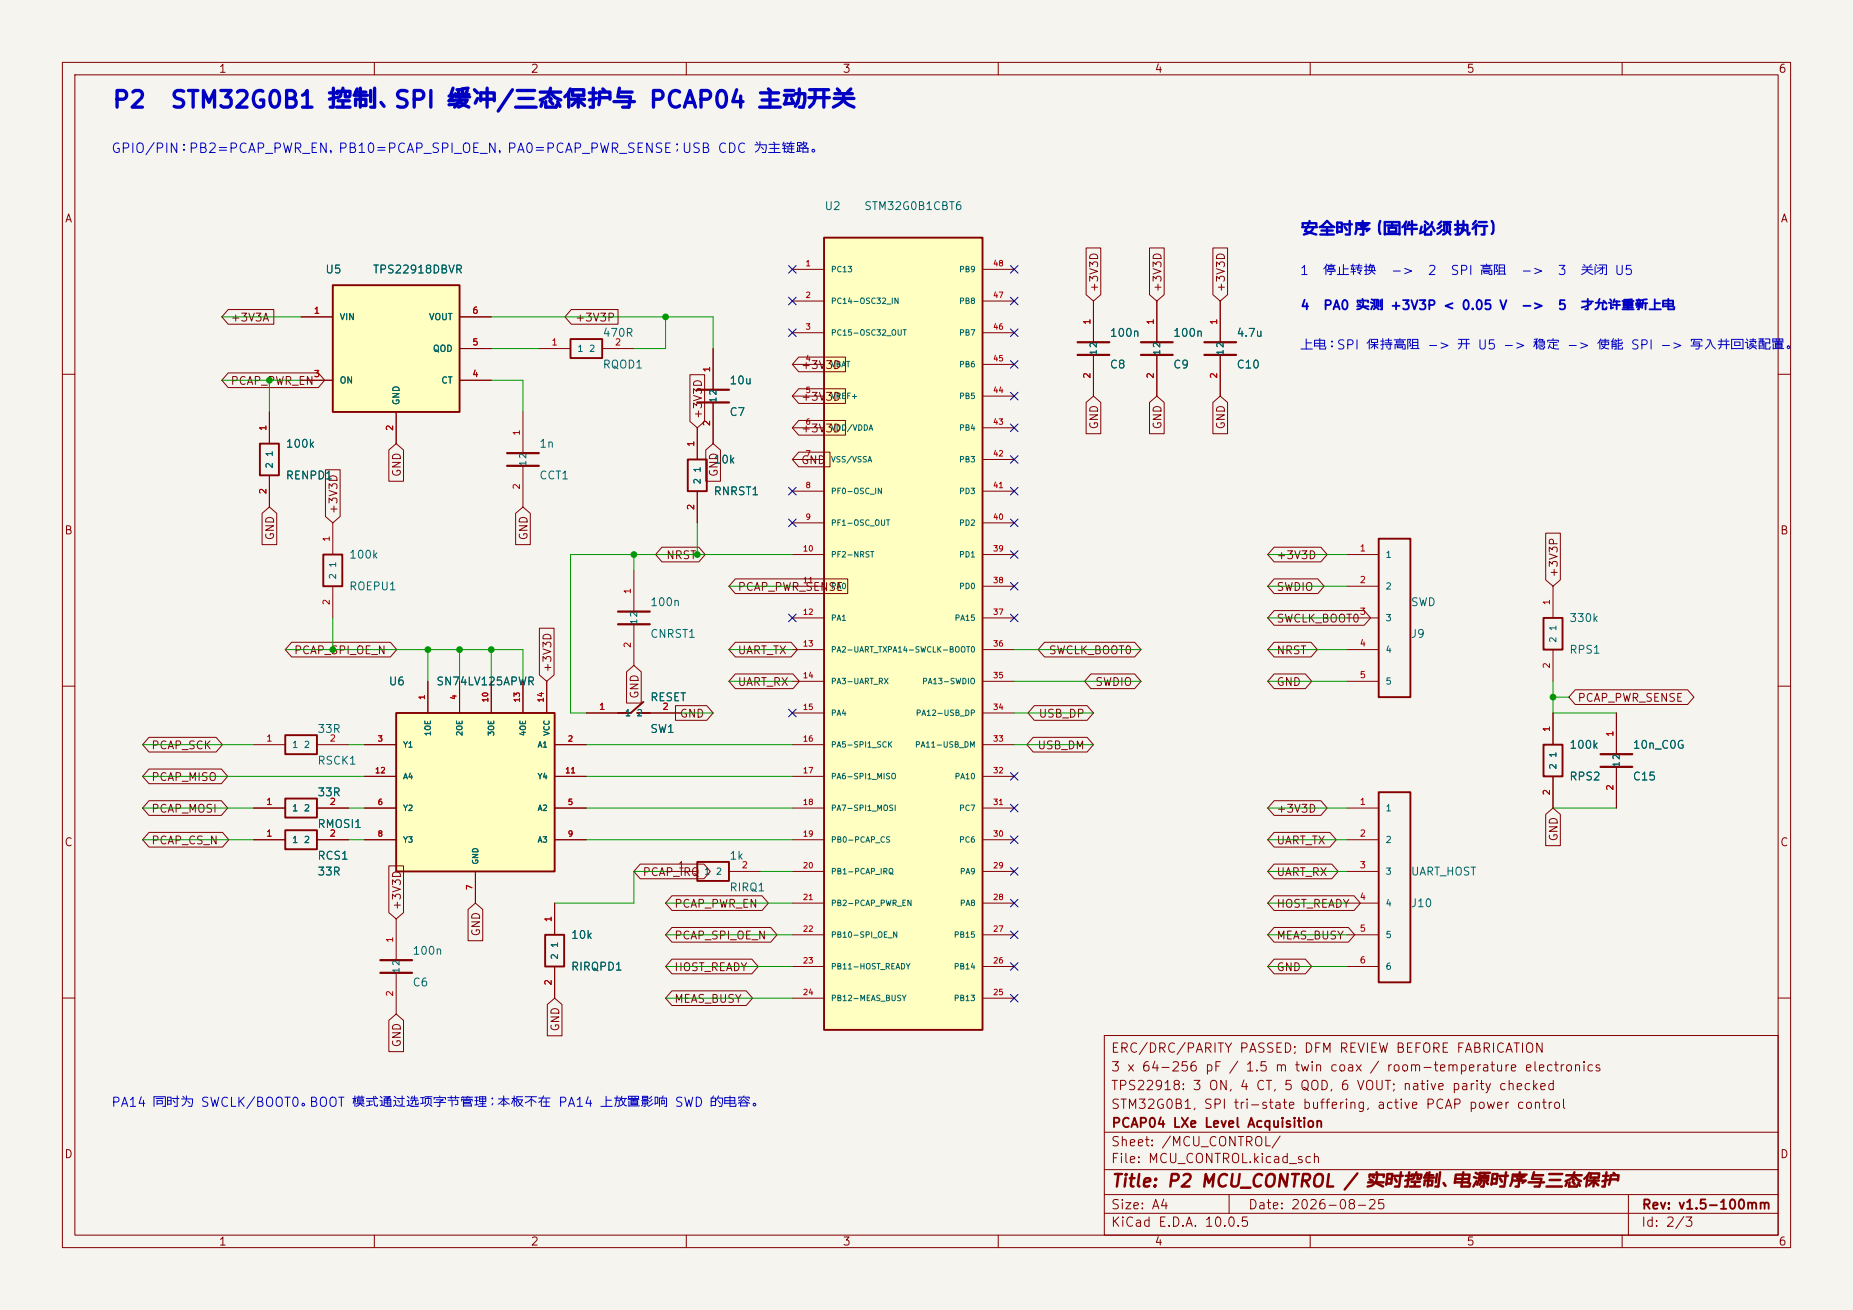
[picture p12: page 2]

P2 STM32G0B1 控制、SPI 缓冲/三态保护与 PCAP04 主动开关

GPIO/PIN：PB2=PCAP_PWR_EN，PB10=PCAP_SPI_OE_N，PA0=PCAP_PWR_SENSE；USB CDC 为主链路。

1 停止转换 -> 2 SPI 高阻 -> 3 关闭 U5

上电：SPI 保持高阻 -> 开 U5 -> 稳定 -> 使能 SPI -> 写入并回读配置。

ERC/DRC/PARITY PASSED; DFM REVIEW BEFORE FABRICATION
3 x 64-256 pF / 1.5 m twin coax / room-temperature electronics
TPS22918: 3 ON, 4 CT, 5 QOD, 6 VOUT; native parity checked
STM32G0B1, SPI tri-state buffering, active PCAP power control
PCAP04 LXe Level Acquisition
Sheet: /MCU_CONTROL/
File: MCU_CONTROL.kicad_sch
Title: P2 MCU_CONTROL / 实时控制、电源时序与三态保护

PA14 同时为 SWCLK/BOOT0。BOOT 模式通过选项字节管理；本板不在 PA14 上放置影响 SWD 的电容。

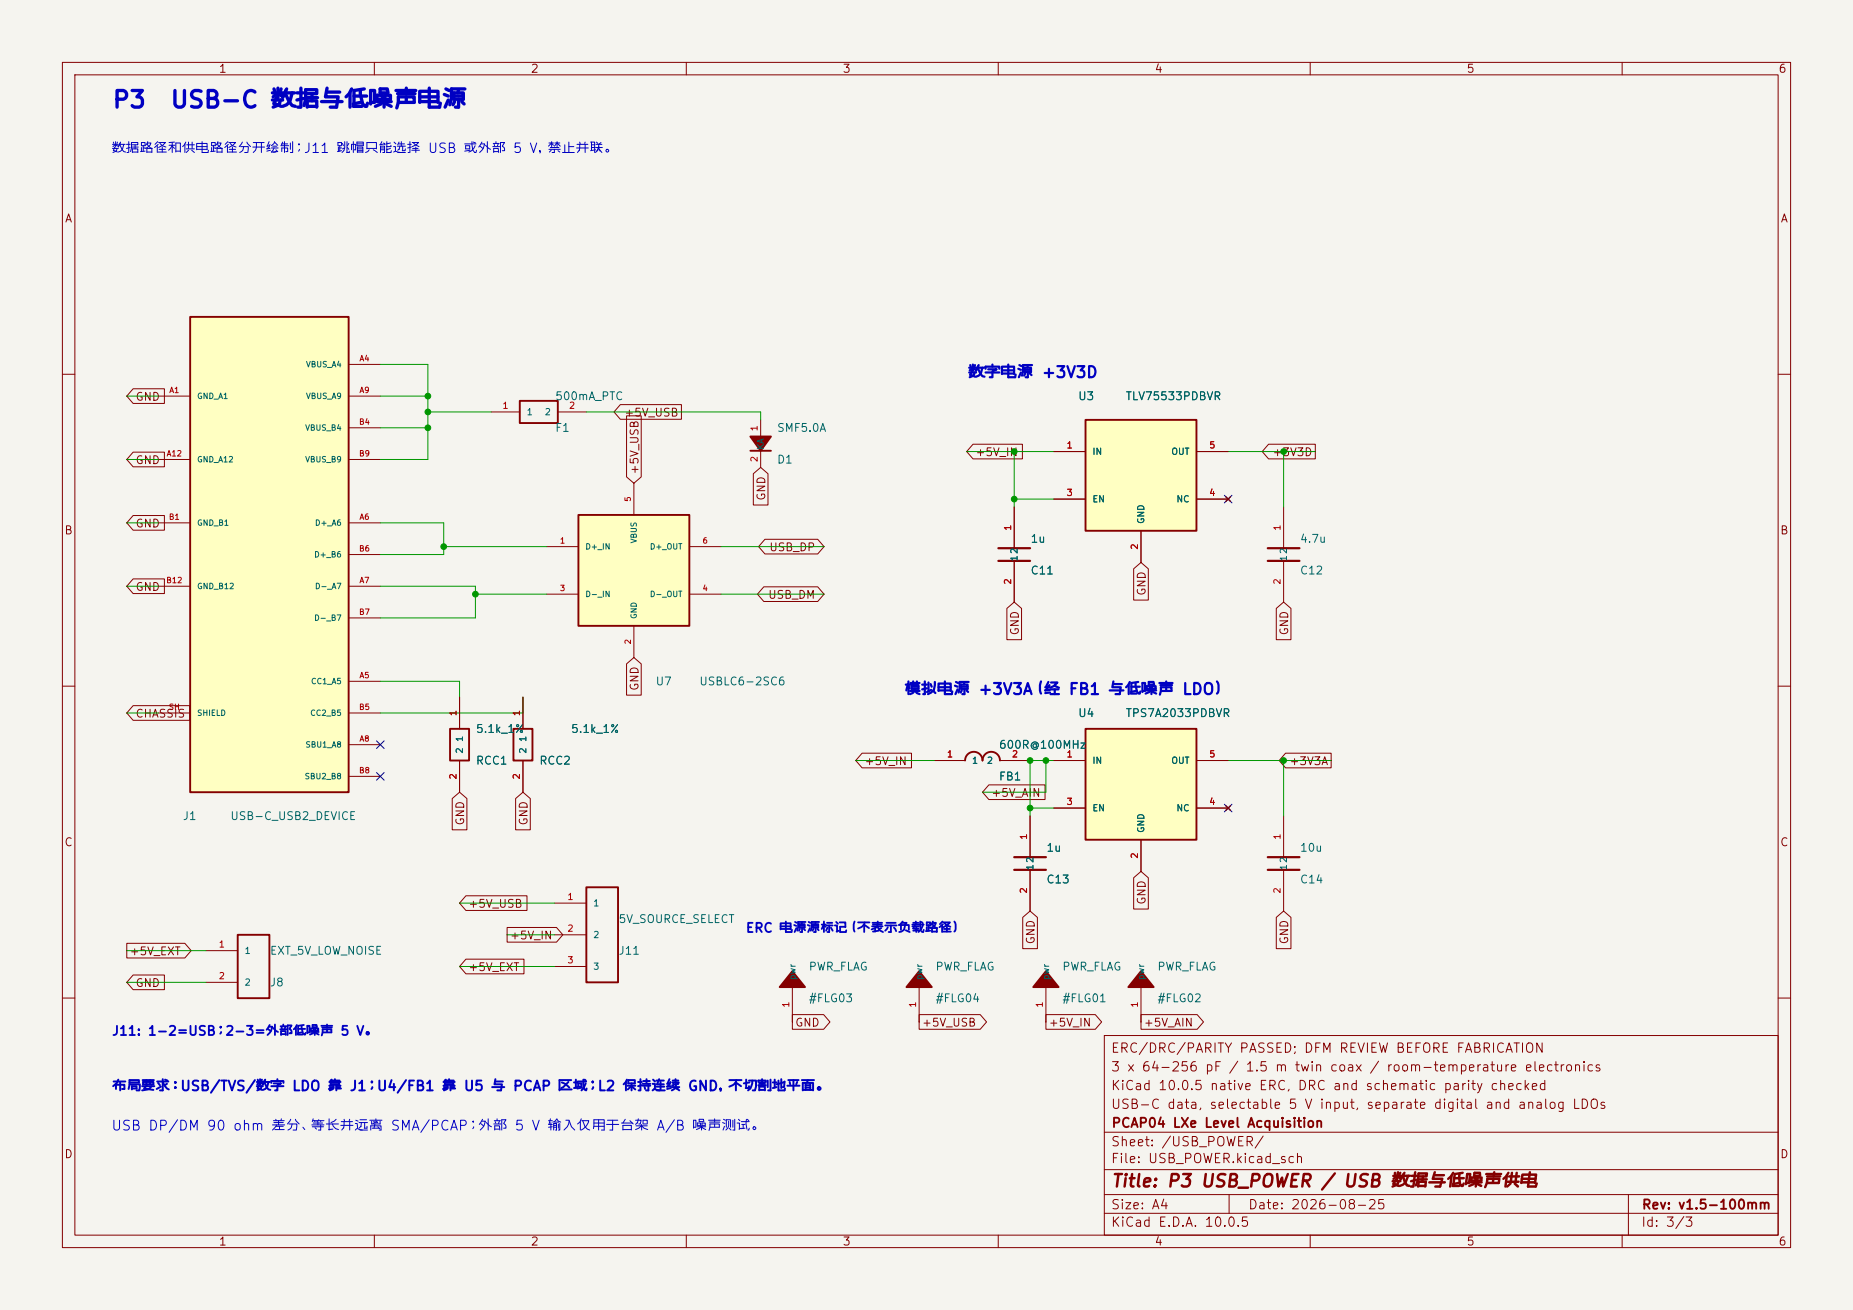
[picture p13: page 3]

数据路径和供电路径分开绘制；J11 跳帽只能选择 USB 或外部 5 V，禁止并联。

ERC/DRC/PARITY PASSED; DFM REVIEW BEFORE FABRICATION
3 x 64-256 pF / 1.5 m twin coax / room-temperature electronics
KiCad 10.0.5 native ERC, DRC and schematic parity checked
USB-C data, selectable 5 V input, separate digital and analog LDOs
PCAP04 LXe Level Acquisition
Sheet: /USB_POWER/
File: USB_POWER.kicad_sch
Title: P3 USB_POWER / USB 数据与低噪声供电

布局要求：USB/TVS/数字 LDO 靠 J1；U4/FB1 靠 U5 与 PCAP 区域；L2 保持连续 GND，不切割地平面。

USB DP/DM 90 ohm 差分、等长并远离 SMA/PCAP；外部 5 V 输入仅用于台架 A/B 噪声测试。

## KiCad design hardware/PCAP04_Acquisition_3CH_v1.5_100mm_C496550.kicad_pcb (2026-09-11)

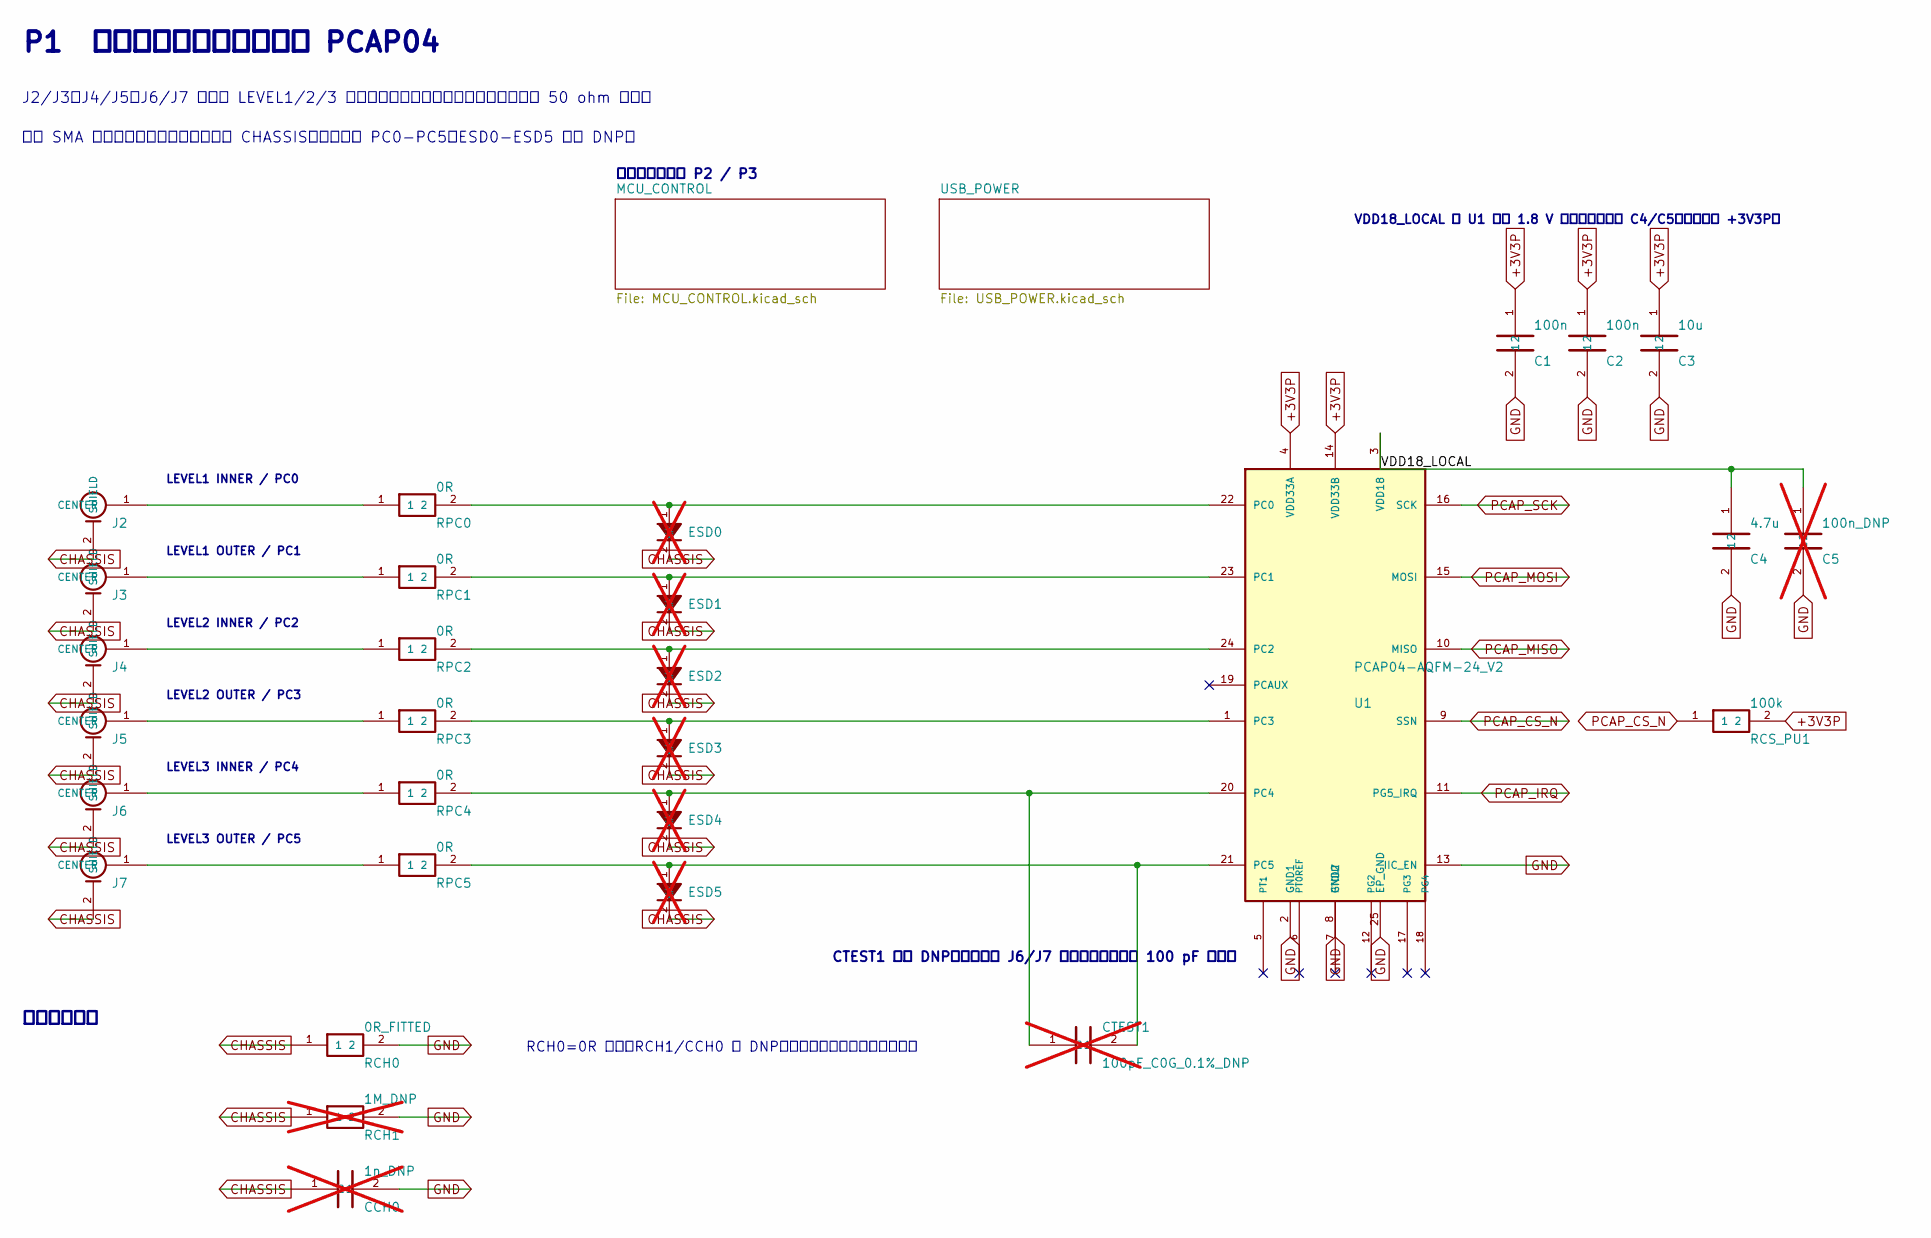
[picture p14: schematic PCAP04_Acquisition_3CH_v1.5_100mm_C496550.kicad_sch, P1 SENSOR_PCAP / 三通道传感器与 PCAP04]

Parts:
C1, C2: 100n; C_0402_1005Metric
C3: 10u; C_0805_2012Metric
C4: 4.7u; C_0603_1608Metric
C5: 100n_DNP; C_0402_1005Metric; not fitted
CCH0: 1n_DNP; C_0603_1608Metric; not fitted
CTEST1: 100pF_C0G_0.1%_DNP; C_0603_1608Metric; not fitted
ESD0, ESD1, ESD2, ESD3, ESD4, ESD5: DNP; D_SOD-882; not fitted
J2, J3, J4, J5, J6, J7: BWSMA-KE-P001 / C496550; SMA_Bat_Wireless_BWSMA-KE-P001_EdgeMount_1.6mm-PCB
RCH0: 0R_FITTED; R_0603_1608Metric
RCH1: 1M_DNP; R_0603_1608Metric; not fitted
RCS_PU1: 100k; R_0402_1005Metric
RPC0, RPC1, RPC2, RPC3, RPC4, RPC5: 0R; R_0402_1005Metric
U1: PCAP04-AQFM-24_V2; QFN-24-1EP_4x4mm_P0.5mm_EP2.7x2.7mm

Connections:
+3V3P: C1.1, C2.1, C3.1, RCS_PU1.2, U1.4 (VDD33A), U1.14 (VDD33B); also elsewhere on the board
/VDD18_LOCAL: C4.1, C5.1, U1.3 (VDD18)
CHASSIS: CCH0.1, ESD0.2 (A), ESD1.2 (A), ESD2.2 (A), ESD3.2 (A), ESD4.2 (A), ESD5.2 (A), J2.2 (SHIELD), J3.2 (SHIELD), J4.2 (SHIELD), J5.2 (SHIELD), J6.2 (SHIELD), J7.2 (SHIELD), RCH0.1, RCH1.1; also elsewhere on the board
GND: C1.2, C2.2, C3.2, C4.2, C5.2, CCH0.2, RCH0.2, RCH1.2, U1.2 (GND1), U1.8 (GND2), U1.13 (IIC_EN), U1.25 (EP_GND); also elsewhere on the board
unnamed: ESD0.1 (K), RPC0.2, U1.22 (PC0)
unnamed: ESD1.1 (K), RPC1.2, U1.23 (PC1)
unnamed: ESD2.1 (K), RPC2.2, U1.24 (PC2)
unnamed: ESD3.1 (K), RPC3.2, U1.1 (PC3)
unnamed: CTEST1.1, ESD4.1 (K), RPC4.2, U1.20 (PC4)
unnamed: CTEST1.2, ESD5.1 (K), RPC5.2, U1.21 (PC5)
unnamed: J2.1 (CENTER), RPC0.1
unnamed: J3.1 (CENTER), RPC1.1
unnamed: J4.1 (CENTER), RPC2.1
unnamed: J5.1 (CENTER), RPC3.1
unnamed: J6.1 (CENTER), RPC4.1
unnamed: J7.1 (CENTER), RPC5.1
PCAP_CS_N: RCS_PU1.1, U1.9 (SSN); also elsewhere on the board
PCAP_IRQ: U1.11 (PG5_IRQ); also elsewhere on the board
PCAP_MISO: U1.10 (MISO); also elsewhere on the board
PCAP_MOSI: U1.15 (MOSI); also elsewhere on the board
PCAP_SCK: U1.16 (SCK); also elsewhere on the board

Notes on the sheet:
LEVEL2 OUTER / PC3
LEVEL3 OUTER / PC5
LEVEL2 INNER / PC2
LEVEL1 OUTER / PC1
LEVEL3 INNER / PC4
RCH0=0R 首装；RCH1/CCH0 均 DNP，不得形成第二个机壳连接点。
LEVEL1 INNER / PC0
J2/J3、J4/J5、J6/J7 分别为 LEVEL1/2/3 浮地电极对；三路均为正式测量通道，无 50 ohm 终端。
全局网络连接到 P2 / P3
CTEST1 默认 DNP；仅在断开 J6/J7 外部探头后装入作 100 pF 自检。
VDD18_LOCAL 是 U1 内部 1.8 V 稳压输出，仅接 C4/C5；严禁连接 +3V3P。
P1 三通道液位传感器输入与 PCAP04
机壳单点连接
每只 SMA 中心接一个电极；全部外壳接 CHASSIS。罐体不接 PC0-PC5；ESD0-ESD5 首板 DNP。

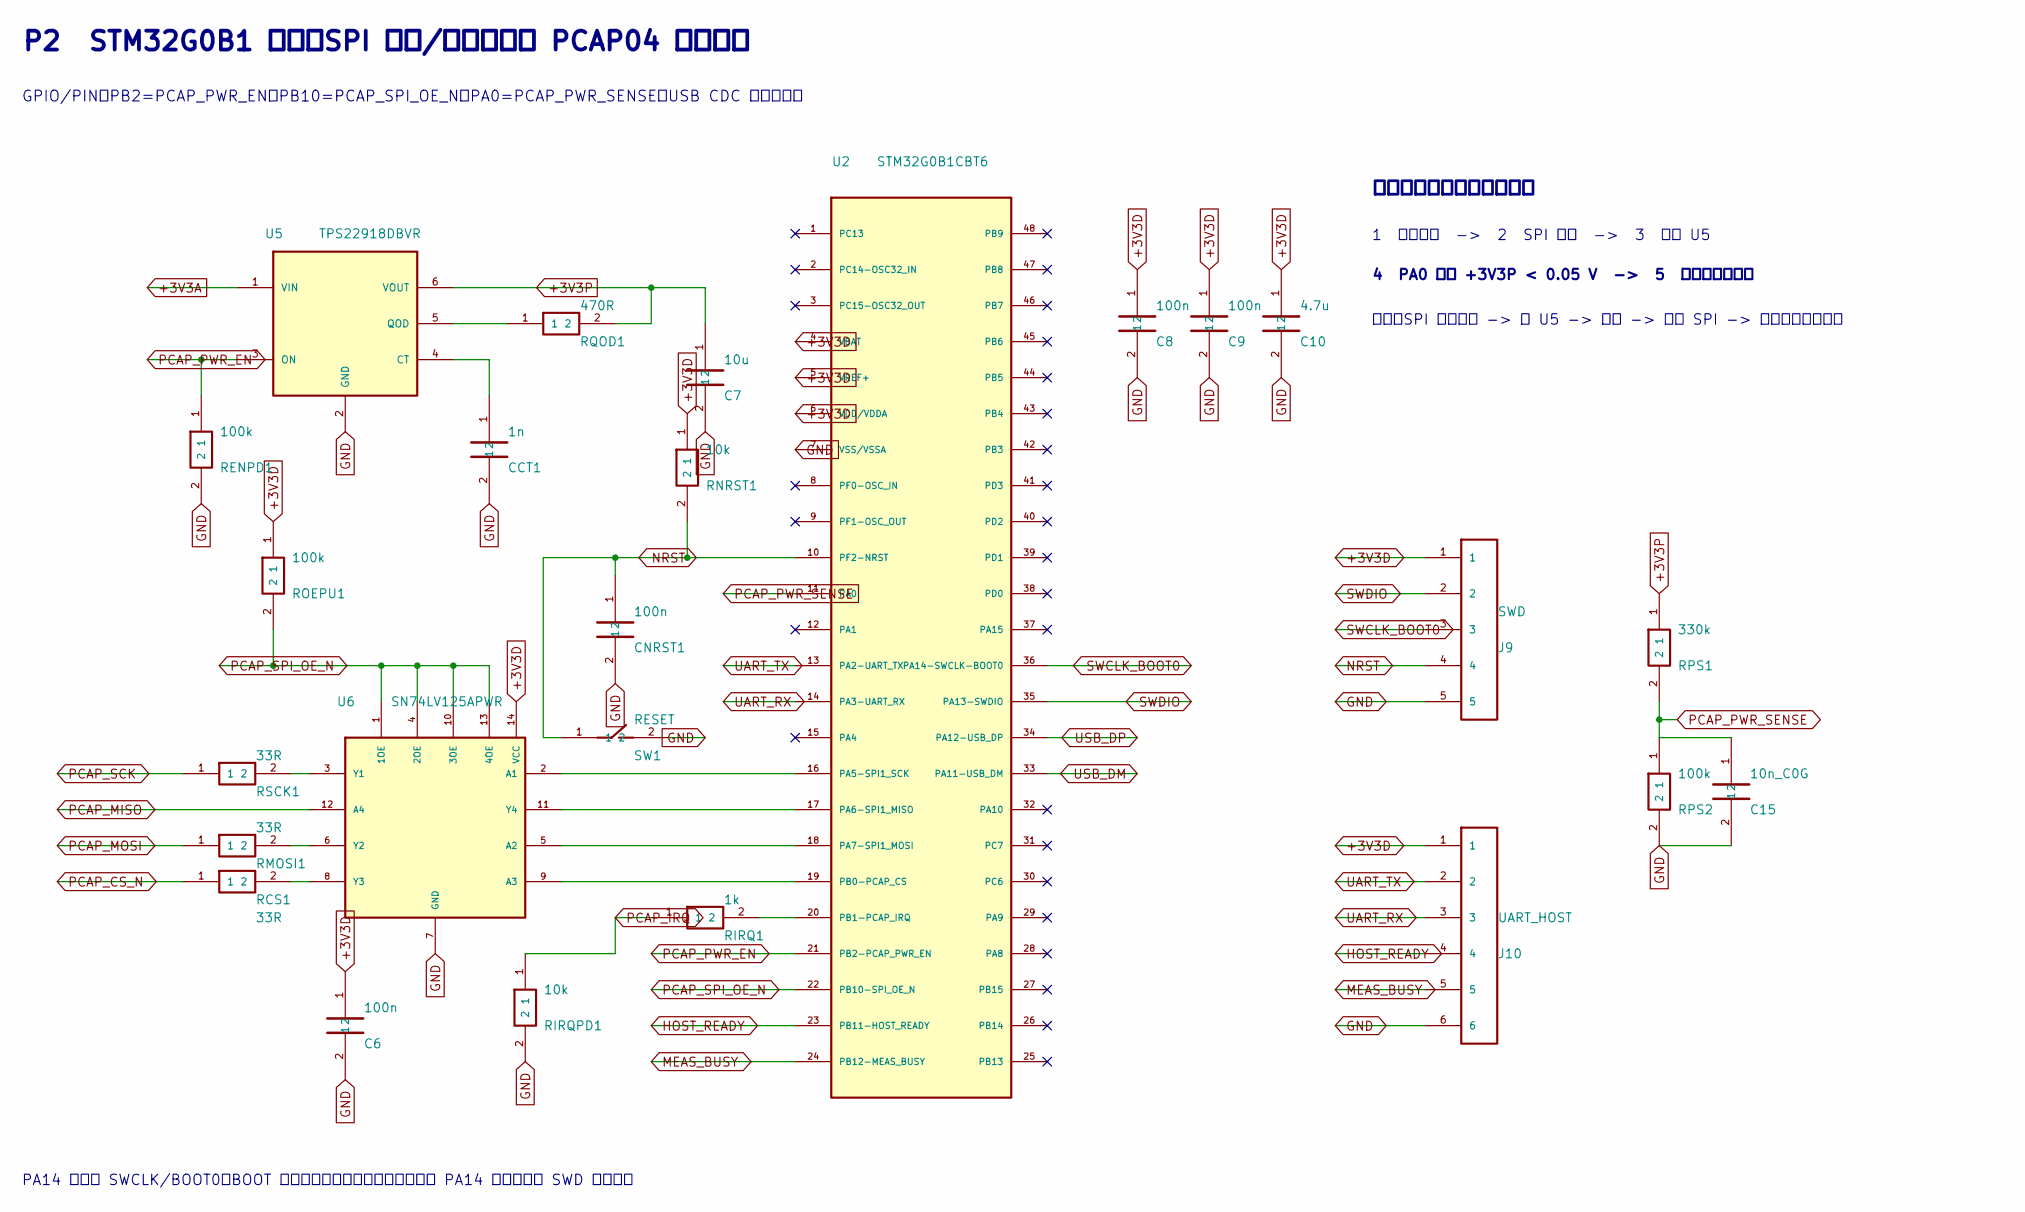
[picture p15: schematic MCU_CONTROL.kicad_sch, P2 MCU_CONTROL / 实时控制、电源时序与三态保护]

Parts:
C6, C8, C9: 100n; C_0402_1005Metric
C7: 10u; C_0805_2012Metric
C10: 4.7u; C_0603_1608Metric
C15: 10n_C0G; C_0402_1005Metric
CCT1: 1n; C_0402_1005Metric
CNRST1: 100n; C_0402_1005Metric
J9: SWD; PinHeader_1x05_P2.54mm_Vertical
J10: UART_HOST; PinHeader_1x06_P2.54mm_Vertical
RCS1: 33R; R_0402_1005Metric
RENPD1: 100k; R_0402_1005Metric
RIRQ1: 1k; R_0402_1005Metric
RIRQPD1: 10k; R_0402_1005Metric
RMOSI1: 33R; R_0402_1005Metric
RNRST1: 10k; R_0402_1005Metric
ROEPU1: 100k; R_0402_1005Metric
RPS1: 330k; R_0402_1005Metric
RPS2: 100k; R_0402_1005Metric
RQOD1: 470R; R_0402_1005Metric
RSCK1: 33R; R_0402_1005Metric
SW1: RESET; SW_SPST_PTS810
U2: STM32G0B1CBT6; LQFP-48_7x7mm_P0.5mm
U5: TPS22918DBVR; SOT-23-6
U6: SN74LV125APWR; TSSOP-14_4.4x5mm_P0.65mm

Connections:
+3V3A: U5.1 (VIN); also elsewhere on the board
+3V3D: C6.1, C8.1, C9.1, C10.1, J9.1, J10.1, RNRST1.1, ROEPU1.1, U2.4 (VBAT), U2.5 (VREF+), U2.6 (VDD/VDDA), U6.14 (VCC); also elsewhere on the board
+3V3P: C7.1, RPS1.1, RQOD1.2, U5.6 (VOUT); also elsewhere on the board
GND: C6.2, C7.2, C8.2, C9.2, C10.2, C15.2, CCT1.2, CNRST1.2, J9.5, J10.6, RENPD1.2, RIRQPD1.2, RPS2.2, SW1.2, U2.7 (VSS/VSSA), U5.2 (GND), U6.7 (GND); also elsewhere on the board
HOST_READY: J10.4, U2.23 (PB11-HOST_READY)
MEAS_BUSY: J10.5, U2.24 (PB12-MEAS_BUSY)
NRST: CNRST1.1, J9.4, RNRST1.2, SW1.1, U2.10 (PF2-NRST)
unnamed: U2.16 (PA5-SPI1_SCK), U6.2 (A1)
unnamed: U2.17 (PA6-SPI1_MISO), U6.11 (Y4)
unnamed: U2.18 (PA7-SPI1_MOSI), U6.5 (A2)
unnamed: U2.19 (PB0-PCAP_CS), U6.9 (A3)
unnamed: RIRQ1.2, U2.20 (PB1-PCAP_IRQ)
unnamed: CCT1.1, U5.4 (CT)
unnamed: RQOD1.1, U5.5 (QOD)
unnamed: RSCK1.2, U6.3 (Y1)
unnamed: RMOSI1.2, U6.6 (Y2)
unnamed: RCS1.2, U6.8 (Y3)
PCAP_CS_N: RCS1.1; also elsewhere on the board
PCAP_IRQ: RIRQ1.1, RIRQPD1.1; also elsewhere on the board
PCAP_MISO: U6.12 (A4); also elsewhere on the board
PCAP_MOSI: RMOSI1.1; also elsewhere on the board
PCAP_PWR_EN: RENPD1.1, U2.21 (PB2-PCAP_PWR_EN), U5.3 (ON)
PCAP_PWR_SENSE: C15.1, RPS1.2, RPS2.1, U2.11 (PA0)
PCAP_SCK: RSCK1.1; also elsewhere on the board
PCAP_SPI_OE_N: ROEPU1.2, U2.22 (PB10-SPI_OE_N), U6.1 (1OE), U6.4 (2OE), U6.10 (3OE), U6.13 (4OE)
SWCLK_BOOT0: J9.3, U2.36 (PA14-SWCLK-BOOT0)
SWDIO: J9.2, U2.35 (PA13-SWDIO)
UART_RX: J10.3, U2.14 (PA3-UART_RX)
UART_TX: J10.2, U2.13 (PA2-UART_TX)
USB_DM: U2.33 (PA11-USB_DM); also elsewhere on the board
USB_DP: U2.34 (PA12-USB_DP); also elsewhere on the board

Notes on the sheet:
上电：SPI 保持高阻 -> 开 U5 -> 稳定 -> 使能 SPI -> 写入并回读配置。
1 停止转换 -> 2 SPI 高阻 -> 3 关闭 U5
PA14 同时为 SWCLK/BOOT0。BOOT 模式通过选项字节管理；本板不在 PA14 上放置影响 SWD 的电容。
GPIO/PIN：PB2=PCAP_PWR_EN，PB10=PCAP_SPI_OE_N，PA0=PCAP_PWR_SENSE；USB CDC 为主链路。
安全时序（固件必须执行）
P2 STM32G0B1 控制、SPI 缓冲/三态保护与 PCAP04 主动开关
4 PA0 实测 +3V3P < 0.05 V -> 5 才允许重新上电

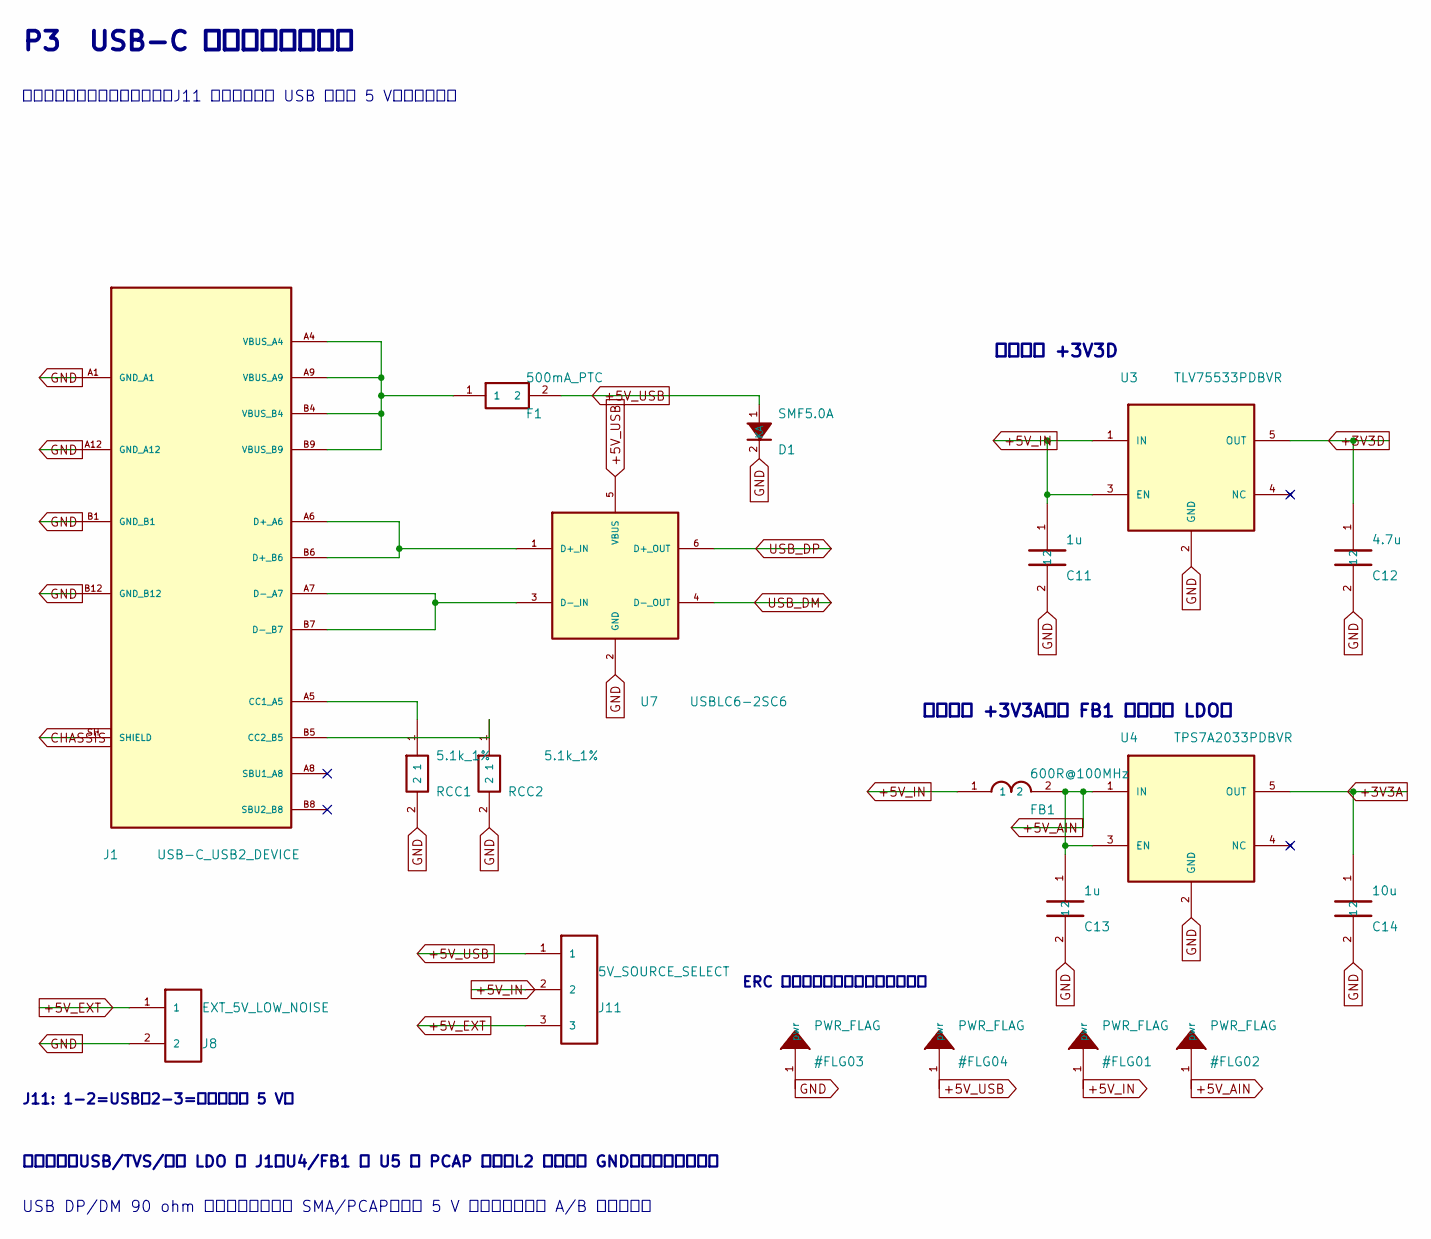
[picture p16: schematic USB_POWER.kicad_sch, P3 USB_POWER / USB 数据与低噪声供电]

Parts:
C11, C13: 1u; C_0603_1608Metric
C12: 4.7u; C_0603_1608Metric
C14: 10u; C_0805_2012Metric
D1: SMF5.0A; D_SOD-123F
F1: 500mA_PTC; Fuse_1206_3216Metric
FB1: 600R@100MHz; L_0603_1608Metric_Pad1.05x0.95mm_HandSolder
J1: USB-C_USB2_DEVICE; USB_C_Receptacle_HRO_TYPE-C-31-M-12
J8: EXT_5V_LOW_NOISE; PinHeader_1x02_P2.54mm_Vertical
J11: 5V_SOURCE_SELECT; PinHeader_1x03_P2.54mm_Vertical
RCC1, RCC2: 5.1k_1%; R_0402_1005Metric
U3: TLV75533PDBVR; SOT-23-5
U4: TPS7A2033PDBVR; SOT-23-5
U7: USBLC6-2SC6; SOT-23-6

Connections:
+3V3A: C14.1, U4.5 (OUT); also elsewhere on the board
+3V3D: C12.1, U3.5 (OUT); also elsewhere on the board
+5V_AIN: C13.1, FB1.2, U4.1 (IN), U4.3 (EN)
+5V_EXT: J8.1, J11.3
+5V_IN: C11.1, FB1.1, J11.2, U3.1 (IN), U3.3 (EN)
+5V_USB: D1.1 (K), F1.2, J11.1, U7.5 (VBUS)
CHASSIS: J1.SH (SHIELD); also elsewhere on the board
GND: C11.2, C12.2, C13.2, C14.2, D1.2 (A), J1.A1 (GND_A1), J1.A12 (GND_A12), J1.B1 (GND_B1), J1.B12 (GND_B12), J8.2, RCC1.2, RCC2.2, U3.2 (GND), U4.2 (GND), U7.2 (GND); also elsewhere on the board
unnamed: J1.A5 (CC1_A5), RCC1.1
unnamed: J1.B5 (CC2_B5), RCC2.1
unnamed: J1.A6 (D+_A6), J1.B6 (D+_B6), U7.1 (D+_IN)
unnamed: J1.A7 (D-_A7), J1.B7 (D-_B7), U7.3 (D-_IN)
unnamed: F1.1, J1.A4 (VBUS_A4), J1.A9 (VBUS_A9), J1.B4 (VBUS_B4), J1.B9 (VBUS_B9)
USB_DM: U7.4 (D-_OUT); also elsewhere on the board
USB_DP: U7.6 (D+_OUT); also elsewhere on the board

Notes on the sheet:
J11: 1-2=USB；2-3=外部低噪声 5 V。
模拟电源 +3V3A（经 FB1 与低噪声 LDO）
USB DP/DM 90 ohm 差分、等长并远离 SMA/PCAP；外部 5 V 输入仅用于台架 A/B 噪声测试。
ERC 电源源标记（不表示负载路径）
布局要求：USB/TVS/数字 LDO 靠 J1；U4/FB1 靠 U5 与 PCAP 区域；L2 保持连续 GND，不切割地平面。
数字电源 +3V3D
P3 USB-C 数据与低噪声电源
数据路径和供电路径分开绘制；J11 跳帽只能选择 USB 或外部 5 V，禁止并联。

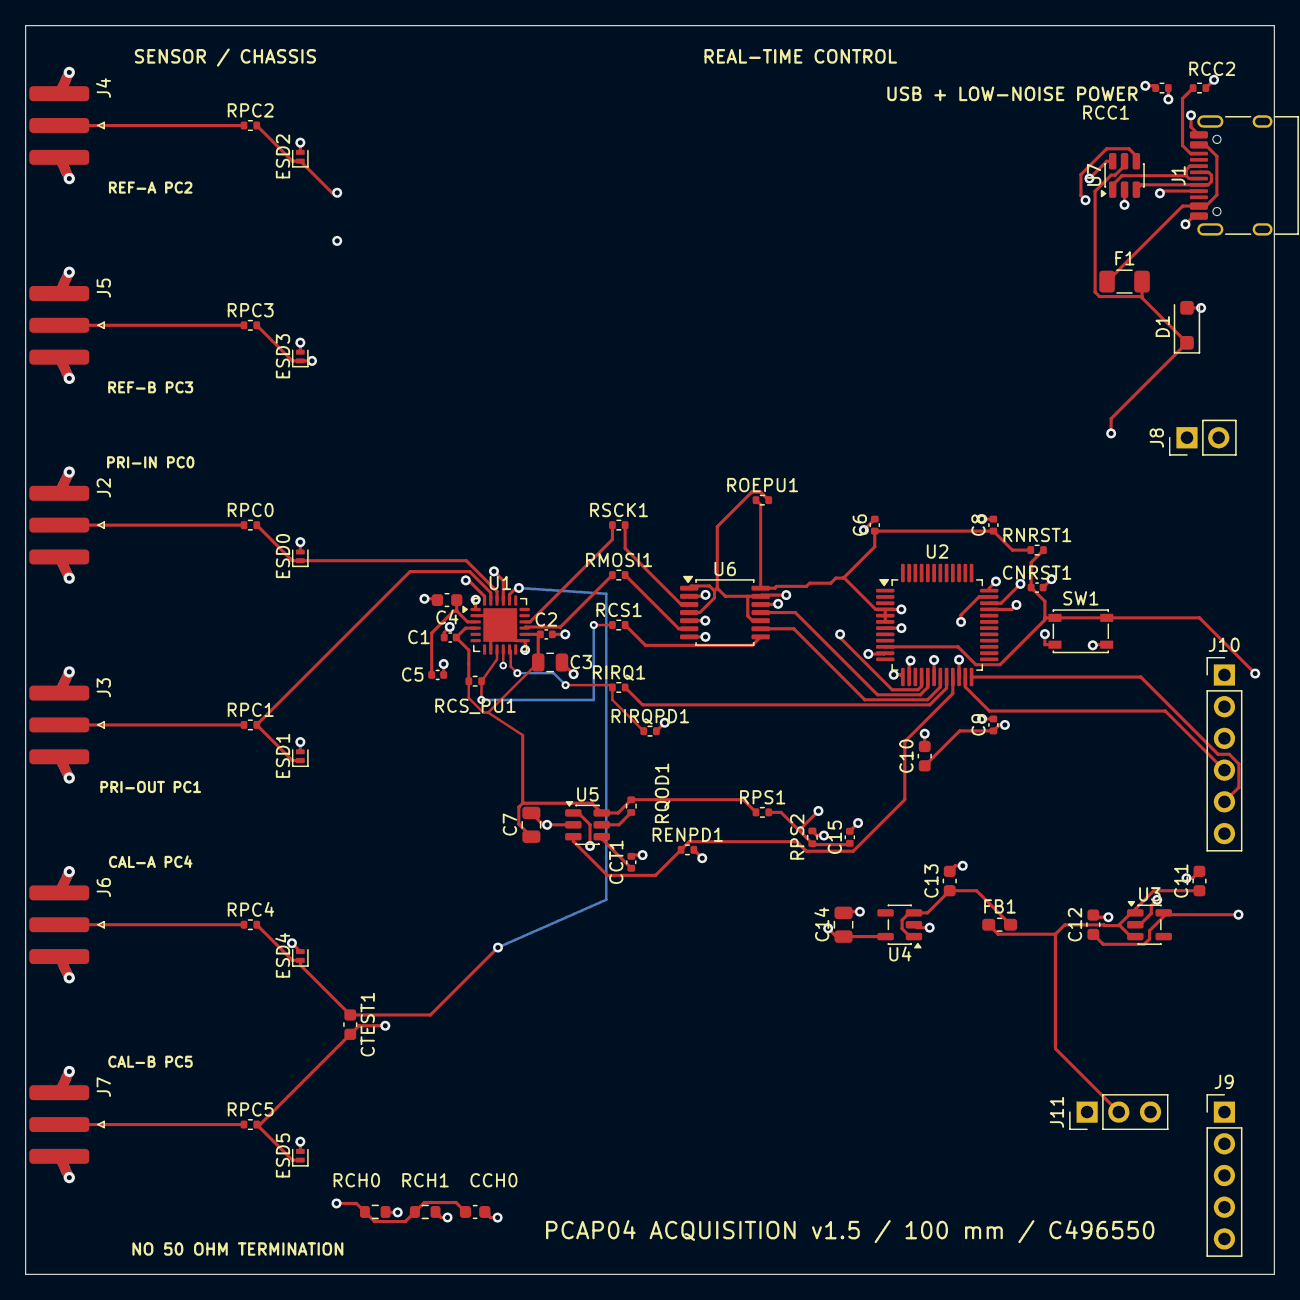
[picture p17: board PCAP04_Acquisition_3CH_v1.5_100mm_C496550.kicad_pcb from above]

Board: 4 copper layers, 100.0 x 100.0 mm, 69 parts (0 on the bottom side), 54 nets.

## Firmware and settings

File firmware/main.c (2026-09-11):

/* SPDX-License-Identifier: MIT */
/* main.c - PCAP04 v1.5 PCAP04 control firmware
 *
 * Console is available over TWO transports simultaneously:
 *   1. a RAM mailbox read/written by the host over SWD  (no extra wires)
 *   2. USART2 on PA2/PA3 -> header J10               (115200 8N1)
 *
 * The firmware never powers the PCAP04 by itself; every rail change follows
 * the sequence written on schematic sheet P2.
 */
#include <stdint.h>
#include <stdarg.h>
#include "stm32g0b1.h"
#include "board.h"
#include "usb_cdc.h"
#include "pcap04_stdfw.h"

/* =====================================================================
 * SWD mailbox console
 * ===================================================================== */
#define MBX_MAGIC0 0x50434150u   /* "PCAP" */
#define MBX_MAGIC1 0x4D42582Du   /* "MBX-" */
#define MBX_TX_SIZE 2048u
#define MBX_RX_SIZE 256u

typedef struct {
    volatile uint32_t magic0, magic1;
    volatile uint32_t version;
    volatile uint32_t tx_size, tx_wr, tx_rd;   /* fw -> host */
    volatile uint32_t rx_size, rx_wr, rx_rd;   /* host -> fw */
    volatile uint32_t heartbeat;
    volatile uint32_t dropped;
    volatile char tx_buf[MBX_TX_SIZE];
    volatile char rx_buf[MBX_RX_SIZE];
} mailbox_t;

static mailbox_t g_mbx __attribute__((section(".mailbox"), used));

/* =====================================================================
 * time base
 * ===================================================================== */
static volatile uint32_t g_ms;
void SysTick_Handler(void) { g_ms++; }
static uint32_t now_ms(void) { return g_ms; }
/* Bounded: if SysTick is ever dead (a stale NVIC/clock state inherited from
 * the ROM bootloader, say) this still returns, so the console always comes up
 * and the board stays debuggable instead of hanging silently at boot.       */
static void delay_ms(uint32_t ms)
{
    uint32_t t0 = g_ms;
    usb_cdc_poll();
    volatile uint32_t guard = ms * 8000u + 200000u;
    while (((g_ms - t0) < ms) && guard) { guard--; usb_cdc_poll(); }
}

/* =====================================================================
 * bounded hardware waits
 *
 * Bring-up firmware must never spin forever on a peripheral flag: one
 * misbehaving block would kill the console and take the board with it.
 * Every wait below gives up after a bounded number of spins and records
 * which one failed, so a stuck peripheral becomes a message, not silence.
 * ~2e6 spins is on the order of 100 ms at 64 MHz.
 * ===================================================================== */
#define SPIN_BUDGET 2000000u

static uint32_t g_timeouts;
#define TO_HSI    (1u<<0)
#define TO_SWHSI  (1u<<1)
#define TO_PLLOFF (1u<<2)
#define TO_FLASH  (1u<<3)
#define TO_PLLON  (1u<<4)
#define TO_SWPLL  (1u<<5)
#define TO_ADCCAL (1u<<6)
#define TO_ADCRDY (1u<<7)
#define TO_CCRDY  (1u<<8)
#define TO_EOC    (1u<<9)
#define TO_SPITX  (1u<<10)
#define TO_SPIRX  (1u<<11)

static const char *const TO_NAME[12] = {
    "HSI-ready", "switch-to-HSI", "PLL-off", "flash-latency", "PLL-lock",
    "switch-to-PLL", "ADC-calibration", "ADC-ready", "ADC-channel-ready",
    "ADC-end-of-conversion", "SPI-TXE", "SPI-RXNE"
};

static int wait_for(volatile uint32_t *reg, uint32_t mask, int want_set, uint32_t flag)
{
    uint32_t spins = SPIN_BUDGET;
    while (spins--) {
        uint32_t v = (*reg) & mask;
        if (want_set ? (v != 0u) : (v == 0u)) { return 0; }
    }
    g_timeouts |= flag;
    return -1;
}

/* =====================================================================
 * clock: HSI16 -> PLL(N=8,M=1,R=2) -> 64 MHz  (RM0444 5.4.4)
 * ===================================================================== */
static void clock_init(void)
{
    /* We may have been entered by a jump from the ROM bootloader with the PLL
     * already running AS the system clock.  Disabling a PLL that is feeding
     * SYSCLK stops the CPU dead, so switch to HSI FIRST, then touch the PLL. */
    RCC_CR |= RCC_CR_HSION;
    wait_for(&RCC_CR, RCC_CR_HSIRDY, 1, TO_HSI);
    RCC_CFGR &= ~RCC_CFGR_SW_Msk;                  /* 000 = HSISYS           */
    wait_for(&RCC_CFGR, RCC_CFGR_SWS_Msk, 0, TO_SWHSI);
    RCC_CR &= ~RCC_CR_PLLON;
    wait_for(&RCC_CR, RCC_CR_PLLRDY, 0, TO_PLLOFF);

    FLASH_ACR = (FLASH_ACR & ~FLASH_ACR_LATENCY_Msk) | FLASH_ACR_LATENCY_2WS
              | FLASH_ACR_PRFTEN | FLASH_ACR_ICEN;

    /* VCO = 16 MHz * 8 = 128 MHz (must be 96..344), R = /2 -> 64 MHz */
    RCC_PLLCFGR = RCC_PLLCFGR_PLLSRC_HSI16 | RCC_PLLCFGR_PLLM(0)
                | RCC_PLLCFGR_PLLN(8) | RCC_PLLCFGR_PLLR(1) | RCC_PLLCFGR_PLLREN;

    RCC_CR |= RCC_CR_PLLON;
    if (wait_for(&RCC_CR, RCC_CR_PLLRDY, 1, TO_PLLON) == 0) {
        RCC_CFGR = (RCC_CFGR & ~RCC_CFGR_SW_Msk) | RCC_CFGR_SW_PLL;
        wait_for(&RCC_CFGR, RCC_CFGR_SWS_Msk, 1, TO_SWPLL);
    }
    /* If the PLL never locks we stay on HSI16: the console still comes up
     * instead of the board going dark.                                     */

    SYST_RVR = (SYSCLK_HZ / 1000u) - 1u;
    SYST_CVR = 0;
    SYST_CSR = 5u;                 /* enable, processor clock, no IRQ...     */
    SYST_CSR = 7u;                 /* ...then enable the tick interrupt      */
}

/* =====================================================================
 * GPIO helpers
 * ===================================================================== */
static void pin_mode(GPIO_TypeDef *g, uint32_t pin, uint32_t mode)
{ g->MODER = (g->MODER & ~(3u << (pin * 2))) | (mode << (pin * 2)); }
static void pin_pull(GPIO_TypeDef *g, uint32_t pin, uint32_t pull)
{ g->PUPDR = (g->PUPDR & ~(3u << (pin * 2))) | (pull << (pin * 2)); }
static void pin_af(GPIO_TypeDef *g, uint32_t pin, uint32_t af)
{ uint32_t i = pin >> 3, s = (pin & 7u) * 4u; g->AFR[i] = (g->AFR[i] & ~(0xFu << s)) | (af << s); }
static void pin_speed_high(GPIO_TypeDef *g, uint32_t pin)
{ g->OSPEEDR |= (2u << (pin * 2)); }
static void pin_set(GPIO_TypeDef *g, uint32_t pin) { g->BSRR = 1u << pin; }
static void pin_clr(GPIO_TypeDef *g, uint32_t pin) { g->BRR  = 1u << pin; }
static uint32_t pin_get(GPIO_TypeDef *g, uint32_t pin) { return (g->IDR >> pin) & 1u; }

/* Bring the control pins up in their SAFE state.  Order matters: the output
 * data register is written BEFORE the pin becomes an output, so the pin never
 * glitches to the wrong level.  (At MCU reset both lines are already held
 * safe by RENPD1 100k pull-down and ROEPU1 100k pull-up on the board.)      */
static void control_pins_init(void)
{
    RCC_IOPENR |= RCC_IOPENR_GPIOAEN | RCC_IOPENR_GPIOBEN;

    pin_set(GPIOB, PIN_SPI_OE_N);            /* 1 = SPI buffer tri-stated    */
    pin_mode(GPIOB, PIN_SPI_OE_N, GPIO_MODE_OUT);

    pin_clr(GPIOB, PIN_PCAP_PWR_EN);         /* 0 = +3V3P off                */
    pin_mode(GPIOB, PIN_PCAP_PWR_EN, GPIO_MODE_OUT);

    pin_set(GPIOB, PIN_PCAP_CS);             /* SSN idle high                */
    pin_mode(GPIOB, PIN_PCAP_CS, GPIO_MODE_OUT);
    pin_speed_high(GPIOB, PIN_PCAP_CS);

    pin_pull(GPIOB, PIN_PCAP_IRQ, GPIO_PULL_UP);   /* INTN is active low     */
    pin_mode(GPIOB, PIN_PCAP_IRQ, GPIO_MODE_IN);

    pin_clr(GPIOB, PIN_HOST_READY); pin_mode(GPIOB, PIN_HOST_READY, GPIO_MODE_OUT);
    pin_clr(GPIOB, PIN_MEAS_BUSY);  pin_mode(GPIOB, PIN_MEAS_BUSY,  GPIO_MODE_OUT);

    pin_mode(GPIOA, PIN_PWR_SENSE, GPIO_MODE_ANALOG);
}

/* =====================================================================
 * USART2 (PA2/PA3, AF1) -> J10
 * ===================================================================== */
static void uart_init(void)
{
    RCC_APBENR1 |= RCC_APBENR1_USART2EN;
    pin_af(GPIOA, PIN_UART_TX, AF_USART2); pin_mode(GPIOA, PIN_UART_TX, GPIO_MODE_AF);
    pin_af(GPIOA, PIN_UART_RX, AF_USART2); pin_mode(GPIOA, PIN_UART_RX, GPIO_MODE_AF);
    pin_pull(GPIOA, PIN_UART_RX, GPIO_PULL_UP);
    USART2->CR1 = 0;
    USART2->BRR = (PCLK_HZ + UART_BAUD / 2u) / UART_BAUD;
    USART2->CR1 = USART_CR1_UE | USART_CR1_TE | USART_CR1_RE;
}
static void uart_putc(char c)
{
    uint32_t guard = 200000u;
    while (!(USART2->ISR & USART_ISR_TXE) && guard--) { }
    USART2->TDR = (uint8_t)c;
}
static int uart_getc(void)
{
    if (USART2->ISR & USART_ISR_ORE) { USART2->ICR = USART_ICR_ORECF; }
    if (USART2->ISR & USART_ISR_RXNE) { return (int)(USART2->RDR & 0xFFu); }
    return -1;
}

/* =====================================================================
 * console output: mailbox + UART
 * ===================================================================== */
static void mbx_putc(char c)
{
    uint32_t wr = g_mbx.tx_wr, nxt = (wr + 1u) % MBX_TX_SIZE;
    if (nxt == g_mbx.tx_rd) { g_mbx.dropped++; return; }   /* host too slow  */
    g_mbx.tx_buf[wr] = c;
    g_mbx.tx_wr = nxt;
}
static void cputc(char c)
{
    if (c == '\n') { mbx_putc('\r'); uart_putc('\r'); usb_cdc_putc('\r'); }
    mbx_putc(c); uart_putc(c); usb_cdc_putc(c);
}
static void cputs(const char *s) { while (*s) { cputc(*s++); } }

static void put_u32(uint32_t v, uint32_t base, uint32_t width, char pad)
{
    char buf[12]; uint32_t n = 0;
    if (v == 0) { buf[n++] = '0'; }
    while (v) { uint32_t d = v % base; buf[n++] = (char)(d < 10 ? '0' + d : 'A' + d - 10); v /= base; }
    while (n < width) { buf[n++] = pad; }
    while (n) { cputc(buf[--n]); }
}
static void cprintf(const char *fmt, ...)
{
    va_list ap; va_start(ap, fmt);
    while (*fmt) {
        if (*fmt != '%') { cputc(*fmt++); continue; }
        fmt++;
        char pad = ' '; uint32_t width = 0;
        if (*fmt == '0') { pad = '0'; fmt++; }
        while (*fmt >= '0' && *fmt <= '9') { width = width * 10u + (uint32_t)(*fmt++ - '0'); }
        switch (*fmt++) {
        case 'u': put_u32(va_arg(ap, uint32_t), 10, width, pad); break;
        case 'd': { int32_t v = va_arg(ap, int32_t);
                    if (v < 0) { cputc('-'); v = -v; }
                    put_u32((uint32_t)v, 10, width, pad); } break;
        case 'x': case 'X': put_u32(va_arg(ap, uint32_t), 16, width, pad); break;
        case 'c': cputc((char)va_arg(ap, int)); break;
        case 's': cputs(va_arg(ap, const char *)); break;
        case '%': cputc('%'); break;
        default: break;
        }
    }
    va_end(ap);
}
/* millivolts -> "3.297 V" */
static void print_mv(uint32_t mv) { put_u32(mv / 1000u, 10, 0, ' '); cputc('.'); put_u32(mv % 1000u, 10, 3, '0'); cputs(" V"); }

/* =====================================================================
 * ADC: +3V3P rail monitor via RPS1/RPS2, referenced to VREFINT
 * ===================================================================== */
static void adc_init(void)
{
    RCC_APBENR2 |= RCC_APBENR2_ADCEN;
    ADC1->CR = ADC_CR_ADVREGEN;
    delay_ms(2);                                   /* >> tADCVREG_STUP 20 us */
    ADC1->CR = ADC_CR_ADVREGEN | ADC_CR_ADCAL;
    wait_for(&ADC1->CR, ADC_CR_ADCAL, 0, TO_ADCCAL);
    delay_ms(1);
    ADC1->CFGR1 = 0;                               /* 12-bit, single shot    */
    ADC1->CFGR2 = ADC_CFGR2_CKMODE_PCLK4;          /* 64/4 = 16 MHz          */
    ADC1->SMPR  = ADC_SMPR_SMP1_160C5;             /* 160.5 clk ~ 10 us      */
    ADC_CCR |= ADC_CCR_VREFEN;
    delay_ms(1);
    ADC1->ISR = ADC_ISR_ADRDY;
    ADC1->CR |= ADC_CR_ADEN;
    wait_for(&ADC1->ISR, ADC_ISR_ADRDY, 1, TO_ADCRDY);
}
static uint16_t adc_read(uint32_t ch)
{
    ADC1->ISR = ADC_ISR_CCRDY;
    ADC1->CHSELR = 1u << ch;
    if (wait_for(&ADC1->ISR, ADC_ISR_CCRDY, 1, TO_CCRDY) != 0) { return 0; }
    ADC1->ISR = ADC_ISR_EOC;
    ADC1->CR |= ADC_CR_ADSTART;
    if (wait_for(&ADC1->ISR, ADC_ISR_EOC, 1, TO_EOC) != 0) { return 0; }
    return (uint16_t)ADC1->DR;
}
static uint32_t vdda_mv(void)
{
    uint16_t cal = *(volatile uint16_t *)VREFINT_CAL_ADDR;
    uint16_t raw = adc_read(ADC_CH_VREFINT);
    if (raw == 0 || cal == 0 || cal == 0xFFFF) { return 0; }
    return (uint32_t)VREFINT_CAL_VREF * cal / raw;
}
/* V(+3V3P) = V(PA0) * (RPS1+RPS2)/RPS2.  See the note in board.h: this board
 * has 33k fitted for RPS1, so the ratio is 1.33 and not the 4.30 of the BOM. */
static uint32_t g_div_num = RAIL_DIV_NUM;
static uint32_t g_div_den = RAIL_DIV_DEN;

static uint32_t rail_mv(void)
{
    uint32_t vdda = vdda_mv();
    uint32_t raw, pa0;
    if (vdda == 0) { return 0; }
    raw = adc_read(PIN_PWR_SENSE);
    pa0 = vdda * raw / 4095u;
    return pa0 * g_div_num / g_div_den;
}

/* =====================================================================
 * SPI1 -> U6 buffer -> PCAP04.  Mode 1 (CPOL=0, CPHA=1), MSB first.
 * ===================================================================== */
static uint32_t g_spi_br = 5u;                     /* PCLK/64 = 1 MHz        */
static void spi_init(void)
{
    RCC_APBENR2 |= RCC_APBENR2_SPI1EN;
    pin_af(GPIOA, PIN_SPI_SCK,  AF_SPI1); pin_mode(GPIOA, PIN_SPI_SCK,  GPIO_MODE_AF); pin_speed_high(GPIOA, PIN_SPI_SCK);
    pin_af(GPIOA, PIN_SPI_MOSI, AF_SPI1); pin_mode(GPIOA, PIN_SPI_MOSI, GPIO_MODE_AF); pin_speed_high(GPIOA, PIN_SPI_MOSI);
    pin_af(GPIOA, PIN_SPI_MISO, AF_SPI1); pin_mode(GPIOA, PIN_SPI_MISO, GPIO_MODE_AF);
    pin_pull(GPIOA, PIN_SPI_MISO, GPIO_PULL_UP);   /* Y4 is Hi-Z when OE_N=1 */
    SPI1->CR1 = 0;
    SPI1->CR2 = SPI_CR2_DS_8BIT | SPI_CR2_FRXTH;
    SPI1->CR1 = SPI_CR1_MSTR | SPI_CR1_SSM | SPI_CR1_SSI
              | SPI_CR1_CPHA                        /* CPHA=1, CPOL=0 = mode1*/
              | (g_spi_br << SPI_CR1_BR_Pos) | SPI_CR1_SPE;
}
static void spi_setbr(uint32_t br)
{
    g_spi_br = br & 7u;
    SPI1->CR1 &= ~SPI_CR1_SPE;
    SPI1->CR1 = (SPI1->CR1 & ~(7u << SPI_CR1_BR_Pos)) | (g_spi_br << SPI_CR1_BR_Pos);
    SPI1->CR1 |= SPI_CR1_SPE;
}
static uint8_t spi_xfer(uint8_t v)
{
    if (wait_for(&SPI1->SR, SPI_SR_TXE, 1, TO_SPITX) != 0) { return 0xFFu; }
    *(volatile uint8_t *)&SPI1->DR = v;            /* 8-bit access is required*/
    if (wait_for(&SPI1->SR, SPI_SR_RXNE, 1, TO_SPIRX) != 0) { return 0xFFu; }
    return *(volatile uint8_t *)&SPI1->DR;
}
static void cs_lo(void) { pin_clr(GPIOB, PIN_PCAP_CS); }
static void cs_hi(void) { pin_set(GPIOB, PIN_PCAP_CS); }

/* =====================================================================
 * escape hatch: double-tap RESET (SW1) enters the ST ROM bootloader
 *
 * Once flash is programmed the chip no longer enters DFU by itself, and the
 * factory default nBOOT_SEL=1 makes the BOOT0 pin (J9-3) inert.  Without this
 * hatch a bad image plus a dead SWD link would be unrecoverable.  RAM keeps
 * its contents across a system reset, so a magic word written for the first
 * 400 ms after boot turns "reset twice quickly" into "enter the bootloader".
 * ===================================================================== */
#define BOOT_MAGIC 0xB007DEADu
static volatile uint32_t g_boot_magic __attribute__((section(".noinit"), used));

/* Set when we have uploaded the ScioSense firmware into the PCAP04's SRAM.
 * Declared here because the rail control below has to invalidate it. */
static uint8_t g_loaded = 0u;

static void safe_shutdown(void);

__attribute__((noreturn)) static void jump_to_bootloader(void)
{
    void (*sysmem)(void);
    uint32_t sp, pc;

    usb_cdc_detach();                      /* let the host see us go away    */
    { volatile uint32_t d = 400000u; while (d--) { } }
    safe_shutdown();                       /* PCAP04 rail off, SPI tri-state */

    __asm volatile("cpsid i");
    SYST_CSR = 0;                          /* stop the tick                  */

    /* back to the reset clock configuration - the ROM code expects HSI16     */
    RCC_CFGR &= ~RCC_CFGR_SW_Msk;
    wait_for(&RCC_CFGR, RCC_CFGR_SWS_Msk, 0, TO_SWHSI);
    RCC_CR &= ~RCC_CR_PLLON;
    wait_for(&RCC_CR, RCC_CR_PLLRDY, 0, TO_PLLOFF);
    FLASH_ACR = (FLASH_ACR & ~FLASH_ACR_LATENCY_Msk);

    /* map system memory at 0x00000000 so the ROM vector table is live       */
    RCC_APBENR2 |= RCC_APBENR2_SYSCFGEN;
    SYSCFG_CFGR1 = (SYSCFG_CFGR1 & ~3u) | SYSCFG_MEM_MODE_SYSTEM;
    __asm volatile("dsb 0xF" ::: "memory");
    __asm volatile("isb 0xF" ::: "memory");

    sp = *(volatile uint32_t *)(SYSTEM_MEMORY_BASE);
    pc = *(volatile uint32_t *)(SYSTEM_MEMORY_BASE + 4u);
    sysmem = (void (*)(void))pc;
    __asm volatile("msr msp, %0" :: "r"(sp));
    __asm volatile("cpsie i");
    sysmem();
    for (;;) { }
}

/* =====================================================================
 * board state + rail sequencing
 * ===================================================================== */
static int g_rail_on, g_bus_on;

static void bus_disable(void) { pin_set(GPIOB, PIN_SPI_OE_N); g_bus_on = 0; }
static void bus_enable(void)  { pin_clr(GPIOB, PIN_SPI_OE_N); g_bus_on = 1; }

/* leave the analogue side in the state the schematic calls safe */
static void safe_shutdown(void)
{
    pin_set(GPIOB, PIN_SPI_OE_N);          /* SPI bus tri-stated             */
    pin_clr(GPIOB, PIN_PCAP_PWR_EN);       /* +3V3P off                      */
    pin_set(GPIOB, PIN_PCAP_CS);
    g_rail_on = 0; g_bus_on = 0; g_loaded = 0u;
}

static int rail_on(void)
{
    uint32_t t0, mv = 0; int i;
    bus_disable();                                  /* step 1: SPI Hi-Z      */
    pin_set(GPIOB, PIN_PCAP_PWR_EN);                /* step 2: U5 ON         */
    t0 = now_ms();
    for (i = 0; i < 400; i++) {
        mv = rail_mv();
        if (mv >= RAIL_ON_MV) { break; }
        delay_ms(1);
    }
    if (mv < RAIL_ON_MV) {
        cprintf("  FAIL +3V3P only reached "); print_mv(mv); cputs(" after 400 ms\n");
        pin_clr(GPIOB, PIN_PCAP_PWR_EN);
        g_rail_on = 0;
        return -1;
    }
    i = (int)(now_ms() - t0);
    g_loaded = 0u;                      /* a fresh rail means a blank PCAP04 */
    delay_ms(PCAP_POWERUP_MS);          /* PCAP04 needs 4 ms; also lets the   */
    mv = rail_mv();                     /* C15 / divider node settle          */
    cprintf("  +3V3P up in %u ms, settled at ", (uint32_t)i); print_mv(mv); cputc('\n');
    g_rail_on = 1;
    return 0;
}
static int rail_off(void)
{
    uint32_t t0, mv = 0; int i;
    bus_disable();                                  /* steps 1-2             */
    pin_clr(GPIOB, PIN_PCAP_PWR_EN);                /* step 3: U5 OFF        */
    t0 = now_ms();
    for (i = 0; i < 1000; i++) {
        mv = rail_mv();
        if (mv <= RAIL_OFF_MV) { break; }
        delay_ms(1);
    }
    g_rail_on = 0;
    g_loaded = 0u;                      /* the PCAP04 just lost its SRAM     */
    if (mv > RAIL_OFF_MV) {
        cprintf("  FAIL +3V3P still at "); print_mv(mv); cputs(" after 1000 ms\n");
        return -1;
    }
    cprintf("  +3V3P discharged below 50 mV in %u ms\n", now_ms() - t0);
    return 0;
}
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
int main(void)
{
    static char line[96];
    uint32_t li = 0;

    uint32_t tap = g_boot_magic;

    /* We may have been entered by a JUMP from the ROM bootloader rather than
     * by a reset.  In that case SYSCFG.MEM_MODE still maps system memory at
     * 0x00000000, so every interrupt would vector through the ROM's table and
     * SysTick would never reach our handler - the first delay_ms() would hang
     * forever.  Point VTOR at our own table and restore the main-flash
     * mapping before anything enables an interrupt.                         */
    __asm volatile("cpsid i");
    SCB_VTOR = 0x08000000UL;
    NVIC_ICER0 = 0xFFFFFFFFUL;    /* the ROM bootloader leaves USB IRQ armed;*/
    NVIC_ICPR0 = 0xFFFFFFFFUL;    /* it would vector into Default_Handler    */
    SYST_CSR = 0;
    RCC_APBENR2 |= RCC_APBENR2_SYSCFGEN;
    SYSCFG_CFGR1 &= ~3u;
    __asm volatile("cpsie i");

    /* Arm the escape hatch FIRST, before any code that could hang.  If the
     * clock setup below ever fails to lock the PLL the magic simply stays
     * armed, so a second reset always gets you into the ROM bootloader.     */
    g_boot_magic = BOOT_MAGIC;

    g_csr_at_boot = RCC_CSR;
    RCC_CSR |= RCC_CSR_RMVF;

    control_pins_init();          /* safe pin states before anything else    */

    /* Still running on the reset clock (HSI16) here, which is exactly what
     * the ROM bootloader expects - so the jump needs nothing but GPIO.      */
    if (tap == BOOT_MAGIC) { g_boot_magic = 0u; jump_to_bootloader(); }

    clock_init();
    delay_ms(400);                /* second tap window                       */
    g_boot_magic = 0u;

    /* publish the mailbox so the host tool can find it at 0x20000000 */
    g_mbx.tx_size = MBX_TX_SIZE; g_mbx.tx_wr = 0; g_mbx.tx_rd = 0;
    g_mbx.rx_size = MBX_RX_SIZE; g_mbx.rx_wr = 0; g_mbx.rx_rd = 0;
    g_mbx.heartbeat = 0; g_mbx.dropped = 0; g_mbx.version = 1;
    g_mbx.magic0 = MBX_MAGIC0; g_mbx.magic1 = MBX_MAGIC1;

    uart_init();
    adc_init();
    spi_init();
    usb_cdc_init();      /* HSI48 + CRS; harmless if the cable is not in */

    cputs("\n\n=== " BOARD_NAME " ===\n");
    cputs("PCAP04 control firmware " FW_VERSION "  (console: SWD mailbox + UART 115200 on J10)\n");
    cputs("console: USB-C CDC + UART 115200 on J10 + SWD mailbox\n");
    cputs("type 'help', or 'selftest' to run everything\n\n> ");

    for (;;) {
        int c = -1;
        usb_cdc_poll();
        /* three console transports, whichever speaks first: the SWD mailbox,
         * the board's own USB-C, and the UART on J10.  Keeping the UART alive
         * means a USB regression can never lock us out of the board. */
        if (g_mbx.rx_rd != g_mbx.rx_wr) {
            c = (int)(uint8_t)g_mbx.rx_buf[g_mbx.rx_rd];
            g_mbx.rx_rd = (g_mbx.rx_rd + 1u) % MBX_RX_SIZE;
        } else if ((c = usb_cdc_getc()) < 0) {
            c = uart_getc();
        }
        if (c >= 0) {
            if (c == '\r' || c == '\n') {
                cputc('\n');
                line[li] = 0; execute(line); li = 0;
                cputs("> ");
            } else if ((c == 8 || c == 127) && li > 0u) {
                li--; cputs("\b \b");
            } else if (c >= 32 && c < 127 && li < sizeof(line) - 1u) {
                line[li++] = (char)c; cputc((char)c);
            }
        }
        g_mbx.heartbeat++;
    }
}

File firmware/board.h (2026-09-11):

/* SPDX-License-Identifier: MIT */
/* board.h - PCAP04_Acquisition_3CH v1.5 (100 mm, C496550) pin map.
 * Derived directly from the v1.5 KiCad netlist; see the design report,
 * Table "Microcontroller pin allocation".
 */
#ifndef BOARD_H
#define BOARD_H
#include "stm32g0b1.h"

#define BOARD_NAME  "PCAP04_Acquisition_3CH v1.5 / 100mm / C496550"
#define FW_NAME     "diag+stdfw+stream+usb"
#define FW_VERSION  "3.3.0"

#define SYSCLK_HZ   64000000u
#define PCLK_HZ     64000000u
#define UART_BAUD   115200u

/* ---- port A ------------------------------------------------------------ */
#define PIN_PWR_SENSE   0    /* PA0  ADC_IN0  <- RPS1/RPS2 divider on +3V3P  */
#define PIN_UART_TX     2    /* PA2  AF1 USART2_TX  -> J10 pin 2             */
#define PIN_UART_RX     3    /* PA3  AF1 USART2_RX  <- J10 pin 3             */
#define PIN_SPI_SCK     5    /* PA5  AF0 SPI1_SCK   -> U6 A1                 */
#define PIN_SPI_MISO    6    /* PA6  AF0 SPI1_MISO  <- U6 Y4                 */
#define PIN_SPI_MOSI    7    /* PA7  AF0 SPI1_MOSI  -> U6 A2                 */
#define AF_USART2       1u
#define AF_SPI1         0u

/* ---- port B ------------------------------------------------------------ */
#define PIN_PCAP_CS     0    /* PB0  -> U6 A3 -> RCS1 -> U1 SSN, active low  */
#define PIN_PCAP_IRQ    1    /* PB1  <- RIRQ1 <- U1 PG5/INTN, active LOW     */
#define PIN_PCAP_PWR_EN 2    /* PB2  -> U5 ON.  HIGH = +3V3P on              */
#define PIN_SPI_OE_N    10   /* PB10 -> U6 1..4OE.  HIGH = bus tri-stated    */
#define PIN_HOST_READY  11   /* PB11 -> J10 pin 4                            */
#define PIN_MEAS_BUSY   12   /* PB12 -> J10 pin 5                            */

/* ---- +3V3P rail monitor ------------------------------------------------ *
 * RPS1 = 330k from +3V3P, RPS2 = 100k to GND, C15 = 10 nF.
 * V(+3V3P) = V(PA0) * (330 + 100) / 100 = V(PA0) * 4.30
 * Source impedance 330k||100k = 76.7 kohm -> longest ADC sample time.       */
/* MEASURED ON THE v1.5 BOARD: RPS1 is fitted as 33k, not the 330k in the BOM.
 * PA0 reads 2.485 V with the rail at 3.30 V  ->  ratio (33+100)/100 = 1.33.
 * The design value would be 430/100.  Override at runtime with 'div n d'.   */
#define RAIL_DIV_NUM    133u
#define RAIL_DIV_DEN    100u
#define RAIL_DIV_NUM_DESIGN 430u
#define RAIL_ON_MV      3000u   /* rail considered up above this             */
#define RAIL_OFF_MV     150u    /* ADC offset x divider ratio sets the floor */

/* ---- PCAP04 serial interface (datasheet SC-001050-DS-6, table 76) ------ *
 * SPI mode 1 (CPOL = 0, CPHA = 1), MSB first.                              */
#define PCAP_OP_WR_CFG   0xA3u   /* 0xA3, 0xC0|addr, data                    */
#define PCAP_OP_RD_CFG   0x23u   /* 0x23, 0xC0|addr, -> data                 */
#define PCAP_OP_RD_RES   0x40u   /* 0x40|addr, -> data                       */
#define PCAP_OP_WR_MEM   0xA0u   /* 0xA0|addr[9:8], addr[7:0], data          */
#define PCAP_OP_RD_MEM   0x20u   /* 0x20|addr[9:8], addr[7:0], -> data       */
#define PCAP_OP_POR      0x88u
#define PCAP_OP_INIT     0x8Au
#define PCAP_OP_CDC_START 0x8Cu
#define PCAP_OP_RDC_START 0x8Eu
#define PCAP_OP_DSP_TRIG  0x8Du
#define PCAP_TESTREAD    0x7Eu   /* == RD_RES addr 62; must return 0x11      */
#define PCAP_SCRATCH_CFG 0x10u   /* FULLCHARGE_TIME: plain data, no side effects */
#define PCAP_SCRATCH_MEM 0x3FFu  /* top of the 1 kB SRAM                     */
#define PCAP_TESTREAD_OK 0x11u
#define PCAP_POWERUP_MS  10u     /* datasheet: operational 4 ms after power  */

#endif /* BOARD_H */

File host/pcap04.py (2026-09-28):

#!/usr/bin/env python3
# SPDX-License-Identifier: MIT
"""
pcap04.py - host-side control of the PCAP04_Acquisition_3CH v1.5 board.

    from pcap04 import PCap04

    with PCap04() as d:
        d.power(True)               # U5 (TPS22918) load switch -> +3V3P
        d.load('f')                 # ScioSense standard firmware, floating
        for s in d.stream(100):
            print(s.pf)             # [ch0, ch1, ch2] in picofarads

Requires firmware v3.0.0 or later on the STM32 (`stream`, `mode`, `avrg`,
`conv`, `refsel`, `comp`, `ports`, `params`, `health`).

Three traps this module exists to keep you out of
--------------------------------------------------
1.  Console framing.  The firmware prints "> " when it is ready.  Some
    commands (`load`) sit in a 500 ms delay in the middle of their output,
    so waiting for a silent gap returns early and the NEXT command is
    written while the firmware is not listening - it is dropped with no
    error at all.  Everything here waits for the prompt.
2.  Duplicate samples.  Polling faster than the conversion rate re-reads the
    same result registers, and a naive standard deviation then comes out as
    exactly 0.  `stream()` is gated on the INTN pin in firmware, and
    `read()` de-duplicates on the raw 32-bit word.
3.  Silent misconfiguration.  A config register write only reaches the
    running conversion after INIT + CDC_START, and the first conversion
    after a restart is usually garbage.  Every setter here restarts and
    drops the settling samples.
"""

from __future__ import annotations

import glob
import json
import os
import re
from pcap_registers import RegisterAccess
import statistics
import sys
import time

if os.name == "nt":
    fcntl = None  # pyserial opens Windows serial ports with exclusive access.
else:
    import fcntl

try:
    import serial
    import serial.tools.list_ports as list_ports
except ImportError:                                          # pragma: no cover
    serial = list_ports = None   # only PCap04() needs it; Sample/Calibration do not

__all__ = ["PCap04", "Sample", "Calibration", "PCapError"]

Q527 = 2.0 ** 27
#: An unconnected floating pair does not sit at exactly 0x7FFFFFFF - it wanders
#: just below it (0x7FFFFF9F was seen).  Anything near the Q5.27 ceiling means
#: "nothing connected", so test the ratio, not the exact word.
SATURATED_RATIO = 15.9
SATURATED = int(SATURATED_RATIO * Q527)

#: floating mode measures PAIRS; grounded mode measures single electrodes
FLOATING_CHANNELS = {0: ("PC0/PC1", "J2/J3"),
                     1: ("PC2/PC3", "J4/J5"),
                     2: ("PC4/PC5", "J6/J7")}
GROUNDED_CHANNELS = {i: ("PC%d" % i, "J%d" % (i + 2)) for i in range(6)}

#: C_AVRG >= 512 measures ~19.5 % low on this board with a ~100 pF sensor.
#: 256 and 257 are both clean, so it is not a low-byte-zero effect - most
#: likely accumulator saturation with large capacitances.  The firmware
#: clamps too; this is here so the host can warn before the round trip.
C_AVRG_MAX = 256

#: measured, not assumed: CONV_TIME = 2000 gave 12.8 Hz
F_OLF_HZ = 51000.0

#: The board's own USB-C console (firmware >= 3.1.0).  pid.codes prototype ID.
#: Matching on this is what stops the tools grabbing the Debug Probe's port,
#: which is the other /dev/cu.usbmodem* on the same machine.
BOARD_VID, BOARD_PID = 0x1209, 0x0001

SPEED_PRESETS = {
    #  name        C_AVRG  CONV_TIME   what you get on a 100 pF sensor
    "fast":      (32,   2000),      # ~12.8 Hz, ~20 fF rms
    "balanced":  (128,  2000),      # ~12.8 Hz, ~6.4 fF rms
    "precise":   (256,  8000),      # ~3.3 Hz,  ~3.9 fF rms
}


class PCapError(RuntimeError):
    pass


# ----------------------------------------------------------------------------
# one conversion
# ----------------------------------------------------------------------------

class Sample:
    """One conversion: raw result registers plus the decoded status."""

    __slots__ = ("t_ms", "host_t", "raw", "status", "_cal", "_mode")

    def __init__(self, t_ms, raw, status, cal=None, mode="f"):
        self.t_ms = t_ms
        self.host_t = time.time()
        self.raw = list(raw)                 # 8 x uint32
        self.status = tuple(status)          # (s0, s1, s2)
        self._cal = cal
        self._mode = mode

    # -- raw ratios -----------------------------------------------------
    @property
    def ratios(self):
        return [r / Q527 for r in self.raw]

    @property
    def n_channels(self):
        return 3 if self._mode == "f" else 6

    @property
    def channels(self):
        """Ratios of the channels that this mode actually measures."""
        return self.ratios[:self.n_channels]

    @property
    def saturated(self):
        """Channels at full scale - almost always nothing connected."""
        return [i for i in range(self.n_channels) if self.is_open(i)]

    def is_open(self, i):
        return self.raw[i] >= SATURATED

    # -- calibrated -----------------------------------------------------
    @property
    def pf(self):
        """Channel capacitances in pF, or None where no calibration exists."""
        if self._cal is None:
            return [None] * self.n_channels
        return [self._cal.to_pf(i, r) for i, r in enumerate(self.channels)]

    # -- status ---------------------------------------------------------
    @property
    def runbit(self):
        return bool(self.status[0] & 0x01)

    @property
    def por_flags(self):
        """Why the PCAP04 last powered on.  These latch at the POR and stay set
        until the next one, so they describe history, not the current
        conversion - a blank chip sitting unprogrammed sets POR_FLAG_WDOG
        every ~10 s, and the flag then survives into a healthy session."""
        s0 = self.status[0]
        out = []
        if s0 & 0x80: out.append("POR_FLAG_WDOG")
        if s0 & 0x40: out.append("POR_FLAG_CONFIG")
        if s0 & 0x20: out.append("POR_CDC_DSP_COLL")
        return out
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

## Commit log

2026-09-11 Initial public release
    Open-hardware PCAP04 3-channel capacitance readout board: KiCad design and
    manufacturing data, bare-metal STM32G0B1 firmware, and Python host tools.
    Contents:
    - hardware/ KiCad 7 project, custom footprints, JLCPCB-ready gerbers (CERN-OHL-P-2.0)
    - firmware/ bare-metal firmware, no vendor HAL, incl. a polled USB CDC-ACM
    device clocked from HSI48+CRS (MIT)
    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
    [MCU_CONTROL.kicad_sch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]
2026-09-11 hardware: add the missing assembly data, library tables and schematic PDF
    The first release shipped only the bare-board fabrication files, so the
    hardware tree was not actually buildable end to end:
    - sym-lib-table was missing entirely, so a fresh clone could not resolve the
    custom PCAP04_Acquisition symbol library
    - the BOM, placement positions and the two ready-to-upload JLCPCB assembly
    packages were all excluded by a blanket *.csv rule in .gitignore; that rule
    is now scoped to host/, where the measurement logs it was written for live
    - no rendered schematic, so the design could not be read without KiCad
    Also drops two dangling library-table entries (a non-existent
    PCAP04_Acquisiti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
    [PCAP04_v1.5_100mm_C496550_BOM_all.csv, PCAP04_v1.5_100mm_C496550_BOM_fitted.csv, PCAP04_v1.5_100mm_C496550_positions.csv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]
2026-09-11 host: keep the unsettled first conversions out of `log` statistics
    `pcap.py log` fed every streamed sample into its accumulator, including the
    first one after a restart, which is not settled and often reads full scale.
    PCap04.collect() already discarded two for this reason; the log path did not.
    On a healthy board that single sample inflated the reported sd from ~40 ppm to
    ~2500 ppm, and because `drift` was just the last value minus the first it also
    reported several tenths of a pF of drift across a run that was flat. Both
    artefacts look exactly like a bad electrode, which is a bad way to spend an
    afternoon.
    The CSV is unchanged - it still records every sample, including the unsettled
    ones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
    [pcap.py]
2026-09-28 Fix Windows serial locking compatibility
    [pcap04.py]
